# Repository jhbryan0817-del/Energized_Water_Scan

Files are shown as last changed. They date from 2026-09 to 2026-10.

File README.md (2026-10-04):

# Energized Water Scanner USV

A small unmanned surface vessel for research into detecting and mapping electrical hazards in flooded areas. Two deployable electrodes, E2/E4, measure voltage difference; the vessel must combine that measurement with validated probe pose, orientation and location. A low reading cannot establish that water is safe.

## Current state — 4 October 2026

**Electronics: Rev H engineering prototype. Mechanical assembly: live Fusion Rev I.** The PCB retains the 91 × 124 mm U-shaped perimeter, 58 × 48 mm motor opening, four mounting holes and 2 mm thickness. Six copper layers accommodate the revised electronics. The live Fusion assembly has been updated for Rev H placement, hull cleanup and corrective closure of obsolete bow/stern openings. Repository 3D exports remain historical; this update contains documentation and BOM changes only. See the [CAD audit](docs/CAD_Audit_2026-10-04.md) for verified results and remaining holds.

- [PCB design, operating limits and assembly](pcb/RevH/README.md)
- [Editable KiCad project](pcb/RevH/EWS_RevH.kicad_pro), [schematic PDF](pcb/RevH/EWS_RevH_schematic.pdf), [PCB BOM](pcb/RevH/BOM.csv), [connector pin map](pcb/RevH/PIN_MAP.md)
- [System design](docs/Design.md), [assembly and procurement](docs/Wiring_and_Assembly.md), [remaining qualification work](docs/Build_Qualification.md)
- [System BOM](BOM.csv): mechanical/harness items plus one assembled carrier. Components on that carrier are listed only in its PCB BOM.

Rev H adds a dedicated ADC per voltage range, hard-wired diagnostic/ready signals, reverse-input protection, a PCB-branch fuse and transient suppressor, battery monitoring and a dry-compartment ingress-sensor interface. The circuit targets sensitive measurements and a separate 600 V RMS, 50/60 Hz fault range. These are unqualified design targets. Bench calibration, insulation/protection review, physical fault testing and environmental qualification remain open. No validated acquisition firmware is supplied.

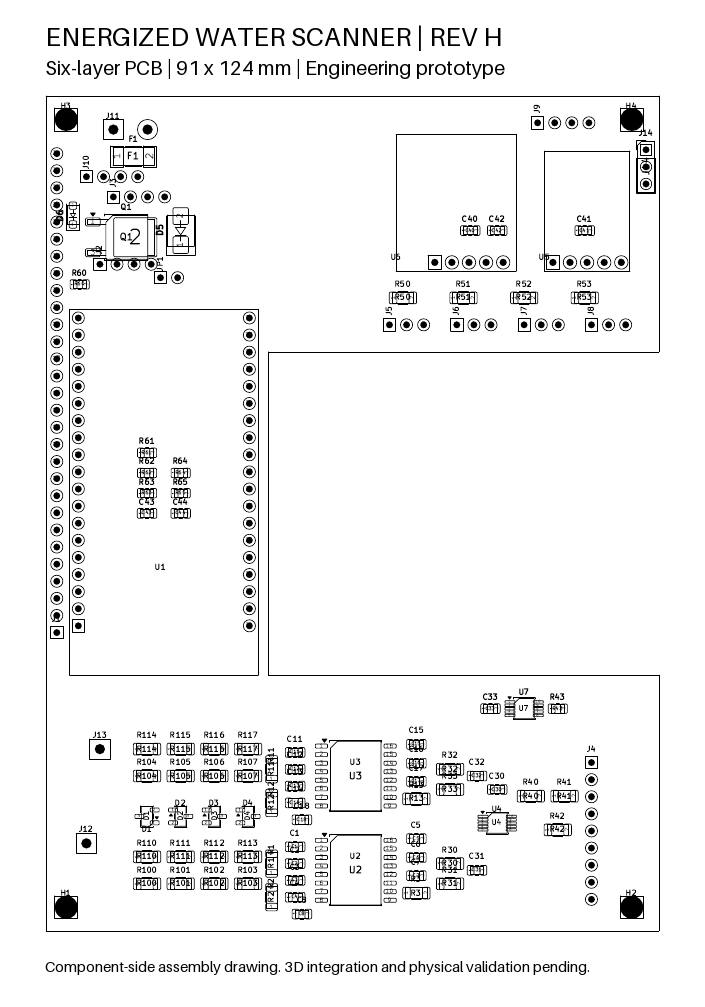
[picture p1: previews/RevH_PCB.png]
Current Rev H PCB assembly drawing


Historical Rev G previews and 3D exports are not the current mechanical authority. Use the saved live `Energized_Water_Scanner` Fusion document.

Two electrodes provide one field projection, not a full 3D field map or a direct measurement of floodwater current. Current-density estimates require independently measured conductivity and a valid field/geometry model. Fast transient measurement and an electrical-safety clearance decision are not released capabilities.

## Next milestones

1. Review the new PCB and validate components, protection, calibration, acquisition timing and fault behavior on a controlled bench.
2. Resolve the remaining mechanical holds in the CAD audit; verify actual components, wiring, seal compression and assembly tolerances.
3. Resolve actuator hardware and sealing, then test the unpowered hull for leakage and loaded flotation.
4. Implement and validate acquisition, invalid-state handling, pose/location logging and mapping; obtain appropriate laboratory qualification before hazardous exposure.

Detailed revision narratives and superseded preview images have been removed from the current documentation; Git history preserves them. Existing exported CAD releases are unchanged and superseded by the live Fusion assembly for this iteration. The `pcb/RevG` files are retained as the historical electrical baseline; use Rev H for new electronics work. Historical scripts and verification records retain their original scope and must not be treated as current acceptance evidence.

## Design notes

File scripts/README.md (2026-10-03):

# Script scope

These retained scripts belong to earlier mechanical and four-probe development revisions. They are not Rev H acquisition firmware or current acceptance tests. In particular, the four-probe gradient/pose assumptions do not apply to the present two-electrode USV. Do not run old Fusion export or mutation scripts against the live assembly without a separate revision-specific review.

Current electronics sources and validation are in `../pcb/RevH/`; current project status and outstanding work are in the root README and `../docs/`. No scripts in this directory were changed in the PCB iteration.

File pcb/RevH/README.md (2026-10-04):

# Energized Water Scanner — PCB Rev H

**Engineering prototype, 3 October 2026.** Native KiCad 10 sources for the two-electrode flood-hazard research USV. Open `EWS_RevH.kicad_pro`. This revision changes electronics only. A subsequent 4 October live Fusion Rev I iteration updates the mechanical fit representation; see [CAD audit](../../docs/CAD_Audit_2026-10-04.md). No new STEP, F3D or STL was generated.

## What changed

- U4 at I2C address **0x48** acquires the high range. New U7 at **0x49** acquires the sensitive range. Both use AIN0–AIN1; each can run continuously at 860 samples/s nominal without alternating ranges. Their clocks are independent, so this is concurrent acquisition, not phase-synchronous sampling.
- Amplifier diagnostics and conversion-ready signals are routed to ESP32 inputs. No diagnostic fly-wires are needed. The existing expansion header still exposes these nets, but they are now reserved.
- J11 feeds F1, then a P-channel reverse-polarity MOSFET Q1. D5 suppresses positive transients on protected VBAT; D6 limits gate-source voltage. Added local rail capacitors supplement the regulator modules.
- A filtered 200 kΩ/33 kΩ battery divider, with 10 kΩ series and 100 nF at GPIO32, feeds ADC1 GPIO32. Its nominal ratio is 7.0606:1 (1.190 V at an 8.4 V battery), with an approximately 41.5 Hz pole. Select and calibrate the ESP32 ADC attenuation accordingly. J14 supports a dry-compartment, 3.3 V, open-drain ingress sensor on GPIO23. This is a powered sensor interface, not a pair of bare-water electrodes.
- Existing high-voltage divider networks, isolation packages, antenna restriction, U-shaped perimeter, motor opening and mounting holes are retained. The schematic, BOM and connector map describe the same board.

## Measurement capability and limits

E2 and E4 measure **signed differential voltage** along one probe separation. The DC-coupled analog circuit also permits AC measurements; initial AC qualification is for 50/60 Hz. These electrodes do not measure total current in floodwater. Under a validated locally uniform field model, the projected field is approximately `E_parallel = V / separation`. Estimating current density further requires conductivity, `J = conductivity × E`; total current also requires a defined area and field distribution. No conductivity sensor is included in this board. Use an independently isolated conductivity instrument if that quantity is needed; the ordinary I2C header is not an isolation barrier.

Two probes can miss a field perpendicular to their separation. A scan must include validated changes in orientation, accurate pose/time/location, immersion verification and invalid-data handling. Position/heading sensors can use the available 3.3 V I2C/UART interfaces; they are not fitted by this revision. DC electrode polarization, electrode material, fouling, contact impedance and motion-generated signals must be characterized separately from electronic DC response.

| Property | High range | Sensitive range |
|---|---:|---:|
| Series resistance per electrode leg | 4 × 249 kΩ | 4 × 249 kΩ |
| Sense resistance per leg | 1 kΩ | 100 kΩ |
| Ideal attenuation before isolation | 997:1 | 10.96:1 |
| Isolation-amplifier differential gain | 2 | 2 |
| Initial measurement target | 600 V RMS, 50/60 Hz; ±850 V DC engineering ceiling | ±2 V instantaneous |
| Initial ADS1115 PGA | ±2.048 V | ±0.512 V |
| Ideal electrode-referred code step | 31.16 mV | 85.63 µV |

These are design calculations, **not demonstrated accuracy, detection thresholds or exposure ratings**. The DC ceiling gives approximately the same divider stress as the crest of the AC target; continuous DC and wet electrochemistry still require separate validation. The low range intentionally clamps during a large fault. Do not use it until recovery has been characterized. PGA changes cannot recover a clipped amplifier signal or improve the amplifier's input offset.

Each differential ADC filter is 1 kΩ + 1 kΩ with 330 nF across the inputs: ideal pole 241 Hz. The ideal analog amplitude factors are approximately 0.979 at 50 Hz and 0.970 at 60 Hz. Include ADC digital-filter response, source loading, capacitor tolerance and temperature in calibration. Neither this pole nor the converter establishes broadband anti-alias performance. Fast impulses, arbitrary inverter spectra and high-frequency hazard characterization are not released capabilities.

At 600 V RMS, the ideal high-range AMC input is 0.851 V peak; its outputs remain approximately 0.589–2.291 V around the nominal 1.44 V common mode. Normal divider dissipation is about 22.5 mW per 249 kΩ resistor. Both channels together load the electrodes by about 1.044 MΩ before clamping and approximately 1 MΩ in a large fault. The source/electrode impedance can therefore produce substantial loading error. Per-resistor working voltage does not establish pulse withstand or a single-fault rating.

The AMC3330's specified input offset alone corresponds to about 0.299 V high-range or 3.29 mV sensitive-range electrode-referred error before calibration. Bias-current mismatch, clamp leakage, resistor matching, temperature and electrode effects add further error. A fine ADC code step is not proof of microvolt detection. Validate range overlap and retain separate calibration coefficients.

## Pin assignments

See [PIN_MAP.md](PIN_MAP.md) and `PIN_MAP.csv` for every connector pin.

| ESP32 GPIO | Rev H use |
|---|---|
| 36, input only | U4 high-range READY, active low; configure ADC conversion-ready mode |
| 35, input only | U7 sensitive-range READY, active low |
| 34, input only | U2 high-range DIAG, active low |
| 39, input only | U3 sensitive-range DIAG, active low |
| 32 / ADC1 | Battery health divider; calibrate ADC attenuation and gain |
| 23 | J14 ingress-sensor input; 10 kΩ pull-up, 1 kΩ series, 100 nF filter |
| 21 / 22 | SDA / SCL, 3.3 V I2C; addresses 0x48 and 0x49 reserved |
| 25 / 26 / 27 / 14 | E2 servo / E4 servo / steering / ESC control |

ADC AIN2 and AIN3 are grounded on each converter. They can support an occasional zero-input diagnostic during a deliberately invalidated acquisition interval. They are not available as general external analog inputs. J4 exposes both isolated-side analog pairs for service, and high READY/DIAG nets; low READY is also on J1 pin 6. Never connect anything on the floating electrode side to J4 or logic ground.

## Power and assembly

Use a **2S battery only**, 8.4 V maximum normal input. An external branch fuse near the battery remains necessary to protect its harness. F1 is a provisional 3 A fast fuse for the PCB branch; coordinate its interrupt rating and time-current curve with available fault current, inrush, connector ratings and measured loads. Motor/ESC propulsion current remains in its separate fused harness. F1 does not protect that harness.

Q1 is deliberately connected with **drain/tab to BAT_FUSED and source to protected VBAT**; reversing those connections defeats reverse-input blocking. At 2 A and the 10 mΩ room-temperature resistance limit quoted at −4.5 V gate drive, its calculated conduction loss is about 40 mW, before temperature increase. This is not a thermal qualification. It is not an ideal-diode controller and does not provide general backfeed isolation between powered sources.

D5 is a 12 V standoff SMBJ12A with a specified 19.9 V clamp at its rated test current. Actual overshoot, lead inductance, pulse energy and fuse coordination need testing. It is a battery-rail suppressor, not an electrode surge arrestor. Do not apply a sustained overvoltage or infer an automotive/load-dump rating. C40/C41/C42 are 25 V X5R parts; C41/C42 sit on 5 V outputs. Check effective capacitance under bias.

Keep combined servo load initially at or below the previous 2 A development limit, with a current-limited supply, and validate stall peaks and trace/via temperatures. Do not infer board current capacity from the D24V50F5 regulator name. New capacitors beneath U5/U6 require component height ≤1.35 mm and a measured ≥2 mm module standoff; check solder joints and module underside components too.

Disconnect the battery and remove JP1 before USB service. The ESP32 can be removed from its sockets. Battery monitoring is not an autonomous cell-balancing, undervoltage-cutoff or battery-management system. Do not leave the battery connected with the MCU supply deliberately removed: divider injection into an unpowered input has not been qualified. J14 is for short internal wiring to a compatible sensor; no exposed floodwater connection or external surge rating is provided. An absent sensor can resemble a dry condition and needs a pre-run functional check.

All GPIO are 3.3 V only. Retain a WROOM DevKitC V4. Flash pins remain unavailable; boot-strapping restrictions still apply to the remaining expansion pins. U5/U6 control pins at J9 are VIN-referenced, not direct GPIO interfaces. Leave the ESC BEC lead disconnected and insulated. Never parallel the regulator outputs.

## Mechanical interface

Six copper layers, 2 mm thickness, 91 × 124 mm overall. Fusion coordinates: X −20…71, Y −62…62 mm. Motor opening: X 13…71, Y −24…24 mm. Four Ø3.4 mm holes: (−17,−58.5), (67,−58.5), (−17,58.5), (67,58.5). KiCad X = Fusion X + 50; KiCad Y = 100 − Fusion Y.

Retain the Rev G 1 mm nylon spacer arrangement, subject to actual screw engagement and underside solder-tail clearance. The existing outline and hole geometry are checked against the previous board. Populated heights, leads, connectors, ESC attachment and hatch clearance must be checked in the next Fusion iteration and on real hardware. The populated fit representation is maintained only in the live Fusion document; it is not a supplier-certified assembly or a manufacturing export.

The nominal six-layer stack uses 70 µm outer and 35 µm inner copper, dielectric layers 0.20/0.30/0.70/0.30/0.20 mm, and 0.01 mm mask per side. It totals 2.00 mm. The fabricator must confirm materials, pressed thickness, tolerances and insulation requirements. No controlled impedance is claimed. The added layers provide space through the restricted neck without reducing the input-isolation rules.

## Verification and next work

**Final automated results: zero ERC violations, zero DRC violations, zero unrouted connections and zero schematic parity issues.** A separate schematic-netlist/board/manifest comparison matched 319 connected pins. Exact Edge.Cuts geometry and the four mounting holes match Rev G. `ERC.json`, `DRC.json`, `verification.json` and `calculations.json` record the checks actually performed. ERC/DRC cannot validate a circuit topology, component derating, electrode performance or electrical safety. Custom copper rules retain the prior 8 mm floating-input-to-logic target and graded internal divider spacing. They do not derive creepage, installation category, pollution degree, laminate CTI or wet-insulation compliance.

Before hazardous exposure, obtain a qualified insulation/protection review and laboratory verification of common-mode and differential exposure, surges, single faults, resistor failures, clamp leakage/recovery, humidity/contamination, dielectric withstand, lead/enclosure insulation and thermal limits. Establish actual sensitivity and calibrated bandwidth using isolated, current-limited laboratory sources. Do not test in occupied energized water. A low reading, broken lead, dry probe, stalled conversion or saturated channel must never be interpreted as safe water.

Firmware is deferred. Its contract is: configure both converters explicitly; timestamp each ready event; detect stale data, clipping, DIAG faults, startup and recovery; invalidate health failures; calculate DC and AC quantities separately; log pose/location and uncertainty. No minimum detectable field or alarm threshold is released.

## Primary references

- [TI AMC3330](https://www.ti.com/lit/ds/symlink/amc3330.pdf): isolated amplifier limits, input/output behavior and supply network.
- [TI ADS1115](https://www.ti.com/lit/ds/symlink/ads1115.pdf): PGA, MUX, I2C addressing and conversion-ready timing.
- [Diodes DMPH3010LK3](https://www.diodes.com/datasheet/download/DMPH3010LK3.pdf): MOSFET pinout and ratings.
- [Littelfuse SMBJ](https://m.littelfuse.com/~/media/electronics/datasheets/tvs_diodes/littelfuse_tvs_diode_smbj_datasheet.pdf.pdf) and [451/453 fuse series](https://www.littelfuse.com/~/media/electronics/datasheets/fuses/littelfuse_fuse_451_453_datasheet.pdf.pdf).
- [Espressif DevKitC V4](https://docs.espressif.com/projects/esp-dev-kits/en/latest/esp32/esp32-devkitc/user_guide.html), [Pololu logic module](https://www.pololu.com/product/2831), [Pololu servo module](https://www.pololu.com/product/2851).

Native files were edited through KiCad's pcbnew API and checked with kicad-cli 10.0.6. The local IPC server answered the version query but returned no open-document handler. No claim of live IPC board editing or physical testing is made.

The native schematic uses project-local functional pin-map symbols with named global nets, continuing the previous project style. It is electrically editable and checked for board parity; it is not a substitute for an independent circuit review. No new fabrication order or manufacturing release is authorized by these reports.

Checks use the configured project rules. The reports list inherited ignored checks, including missing courtyards, track-to-via centering and footprint filters. No new violation was excluded to obtain the result. Mechanical fit of parts above sockets or module standoffs remains a separate check. The archive intentionally excludes 3D models; references inherited from Rev G are represented in the live Fusion fit assembly, with provisional envelopes identified in the CAD audit.

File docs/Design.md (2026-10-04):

# Current system design

The USV is intended to detect and map electrical hazards remotely in flooded areas. The hull is 320 mm long, with a documented 125.2 mm bottom beam and 170 mm hatch flange. Only the inner E2/E4 probe mechanisms remain. Each uses a dry HS-65HB servo and a nominal timing transmission to a sealed shaft and insulating 166 mm arm. Nominal exposed-head separation at symmetric deployment is 114.6 mm; actual submerged geometry must be measured. Varying orientation is necessary to address the blind direction of a single electrode pair.

The current mechanical authority is live Fusion Rev I; see the [CAD audit](CAD_Audit_2026-10-04.md). The U-shaped carrier replaces the former electronics tray; the ESP32 is socketed on it. The old rear controller shelf and electronics capture bridges are absent. The battery cradle, propulsion mounts/tube, steering saddle, rudder, wet-channel roofs, probe covers and sealing features remain functional. There are 13 documented print bodies in the existing Rev G release. The Rev H electronics iteration did not change geometry. This subsequent Rev I mechanical iteration cleans the exterior hull relief and integrates a Rev H fit representation without exporting 3D files.

The two electrode leads feed protected sensitive and high-voltage paths through separate isolated amplifiers. Rev H uses one ADC per range and wired health/ready signals. Logic and servo supplies remain separate; propulsion current stays in an external fused harness. Refer to the [PCB guide](../pcb/RevH/README.md) for the authoritative electrical circuit, pin map, measurement limits and board interface.

The measurement is differential voltage. A field estimate requires electrode spacing and pose; current density further requires conductivity. DC electrode polarization, fouling, motion, field orientation and probe immersion can invalidate apparent electrical readings. No conductivity, GNSS or heading module is fitted in the current BOM. Expansion interfaces provide room for subsequent integration, with isolation required for any additional wet sensing interface.

Current CAD images are geometric references, not photographs of a built vessel. CAD fit, electrical rule checks and nominal supplier dimensions do not establish waterproofness, electrical safety, reliable actuation or flotation. The [qualification plan](Build_Qualification.md) separates those remaining tasks.

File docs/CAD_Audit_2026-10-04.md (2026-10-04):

# Live Fusion CAD audit — 4 October 2026

Status: CAD iteration saved in Fusion; prototype qualification remains open. The active document reports isSaved=true and isModified=false after the final inspection.

## Sources and scope

The live `Energized_Water_Scanner` Fusion document is the mechanical authority. Repository STEP, F3D and STL files are historical and were not used as the current geometry. No new 3D exports are part of this iteration. Electronics remain Rev H and were inspected read-only from the 3 October engineering package.

PCB SHA-256: `632b1010472cf8494d2aebf4daa54a68f1dddf9a889bf5f3b36ea65f5c8ed012`. The board contains 100 footprints: 99 manifest entries plus the M1 ESC mounting allocation. Manifest placement coordinates match the board. Explicitly unconnected ESP32 flash pins and J8 pin 2 are intentional. No circuit, routing or footprint change is authorized by this mechanical iteration.

## Hull cleanup

The initial hull was a single solid with 902 BRep faces, including 582 planes, 154 cylindrical faces and 166 NURBS faces. Faces are not equivalent to mesh triangles or leaks. Adjacent coplanar-face inspection found no simple redundant planar seams to merge.

Removing the raised lettering on the negative-Y exterior panel reduced the hull to 667 faces (235 fewer, 26.1%). The underlying panel plane was retained. Volume changed from 543.530832 to 543.175890 cm³, a removal of 354.942 mm³ of exterior relief. The result is still one solid and one lump, with the original overall bounding box. The original hull remains hidden as `ARCHIVE_RevG_Hull_DO_NOT_BUILD`; that initial replacement was subsequently superseded by the opening repair below.

A delete-and-heal operation on a duplicate caused Fusion to close. The saved original was reopened, and the successful cleanup used a bounded Boolean cut in temporary geometry before adding the verified result. This is a limited simplification, not a wholesale hull reconstruction. Hundreds of remaining faces encode mounting bosses, pilots, channels, roof boundaries and other functional geometry.

## Corrective bow and stern repair

The initial audit missed large openings at the bow and stern. A valid solid and a PCB clearance pass did not establish continuity of the water boundary. The user identified this omission; the initial hull cleanup must not be interpreted as closure of those openings.

The active hull is now `PRINT_01_Hull_shell_RevI_repaired`. Obsolete pockets that broke through the transom and bow have been closed with continuous skins following the adjacent hull planes. The starboard stern chine breakthrough was also closed. The transom and bow skins span 3.3 mm in X (approximately 3.2 mm normal thickness); the chine repair uses 3 mm normal thickness. Existing adjacent geometry remains, so this is not a uniform-wall guarantee. The 7 mm steering passage and four 2.5 mm rudder-bracket bores are retained. No component was moved, and the probe deployment channels remain open intentionally.

Final geometry: **694 faces**, one solid, one lump, one shell, volume **550.479057 cm³**. That is 208 fewer faces than the original 902 (23.1%). Two enclosed remnants of obsolete bow pilot bores were filled rather than leaving trapped cavities. The initial and intermediate hulls are hidden archive components, not additional build parts.

Verification includes exterior views of both ends, Boolean intersection checks of the final hull against 316 nearby retained bodies (zero intersections above 0.0001 mm³), and a 1 mm grid through the repaired wall interiors. The grid excludes functional bores and panel boundaries: 7,078 transom points and 6,670 bow points. Missing material dropped from 1,443 and 320 sampled points respectively to zero. This is a targeted continuity check, not an exhaustive leak-path proof or physical pressure test. Dynamic seals, fasteners, feedthroughs, print porosity and the hatch still require the qualification below.

## PCB mechanical contract

Board: 91 × 124 × 2 mm, X −20…71 mm, Y −62…62 mm. Opening: X 13…71, Y −24…24 mm. Four Ø3.4 mounting holes at (−17,−58.5), (67,−58.5), (−17,58.5), (67,58.5). PCB underside Z=33 mm, top Z=35 mm in the retained assembly coordinate system. KiCad coordinates convert by X_Fusion=X_KiCad−50 and Y_Fusion=100−Y_KiCad.

The fit representation is not a fabrication model: it represents board outline and mounting holes, package bodies, module/header envelopes and explicitly labelled provisional allocations. Copper and individual electrical drills are not rendered. The KiCad board remains authoritative for manufacturing.

## Verified configuration and clearance result

The saved Fusion document is `Energized_Water_Scanner`, data-file ID `urn:adsk.wipprod:dm.lineage:ybjJzCieRSuTtp7MFNwhCA`. The active `PCB_RevH_populated_RevI_fit` contains 243 bodies representing the carrier and all 95 populated references. The preceding PCB and hull are retained as hidden archive components; the imported package library is hidden and is not an assembly item.

Q1, D5, D6 and the 0805 resistor use installed KiCad package geometry. Existing module/header representations were reused at Rev H placements. F1 is a provisional 6.2 × 2.8 × 3.1 mm envelope, not a supplier maximum-tolerance envelope. J11–J13 represent pigtail termination space, not complete wire routes. J14 uses a generic header representation; verify the selected connector and mating half. Module bodies and sockets must be checked against purchased parts.

A bounding-box broad phase followed by temporary BRep Boolean intersections found **zero positive-volume intersections above 0.0001 mm³** between the 243 PCB-fit bodies and the other retained modeled bodies, including the hidden hatch/gasket. Archive and library components were excluded. This does not test contacts, PCB-to-package overlaps, cable routing, tool access, motion sweeps or manufacturing tolerances. The hull has one solid, one shell and one lump. Its intentional functional passages were retained; no claim is made that every apparent opening has been sealed.

The 1 mm spacers place the PCB underside at Z33 mm. Modeled header tails reach Z32.2 mm, leaving only 0.2 mm above the Z32 support-top plane where that plane is present. This is a nominal geometry observation, not adequate guaranteed clearance for solder fillets and print variation. Resolve the stack with the actual connectors before manufacture.

## Water boundary and assembly risks

| Priority | Interface | Finding and required disposition |
|---|---|---|
| High | Propulsion shaft | A bonded stern tube does not seal the annulus between rotating shaft and tube. Qualify a real dynamic seal/lubrication arrangement and axial retention before immersion. |
| High | Probe shaft cartridges | Nominal seal, shaft and bushing envelopes do not establish water duty, shaft finish, interference fits, wear or drag. Release machined cartridge tolerances against the selected seal supplier and shaft specification. |
| High | Steering boot | The current boot is an allocation, not a selected and tested water seal. Verify both retained ends, linkage sweep, buckling and repeated cycles. |
| High | Lead feedthroughs | Potting requires validated bond to the actual wire jacket and printed/coated hull, void control and strain relief. Protect the flex loop throughout probe travel. |
| High | Hull and wet-channel roofs | A watertight BRep solid does not prove the assembled dry compartment is sealed. Inspect all through passages, roof joints and fastener breakthroughs, then perform unpowered leak tests after coating. |
| Medium | Main hatch | The initial CAD shows a 2 mm gasket at Z68…70 and cover at Z70…73: nominal uncompressed geometry, not demonstrated gasket squeeze. Select material and compression specification, verify flatness and use controlled tightening/appropriate stops. |
| Medium | PCB underside | Retained 1 mm spacers leave little margin for solder tails, solder fillets and printed boss variation. Trim/inspect leads and validate the complete assembled stack; do not deepen wet-side blind pilots to gain screw engagement. |
| Medium | Regulator modules | C40/C41/C42 occupy space under modules. Require ≥2 mm actual clearance to the module underside, capacitor height ≤1.35 mm, and allowance for solder and tolerances. Nominal gap is not a tolerance analysis. |
| Medium | Probe service covers | They are removable access covers, not independently sealed compartments. Retain connector access and validate E4 inward-then-upward removal with wiring installed. |
| Medium | Belts and pulleys | Smooth pulley bodies do not specify tooth profile, horn adaptation, belt availability, tension adjustment or axial retention. Confirm one complete actuator before duplicating it. |
| Medium | Battery and ESC | Confirm strap routing, flush screw heads, abrasion protection and removal path. Qualify the ESC attachment adhesive and temperature; keep all wiring off gasket lands. |

No IP rating, full-motion assembly acceptance, minimum wall-thickness certification or physical leak result is claimed. Before a build release, perform tolerance-stack review with supplier tolerances and the actual printing/machining process. Test the empty hull and each dynamic penetration in unenergized water, then repeat after service and actuation cycles. Establish freeboard and stability using the actual completed mass.

## Read-only electrical assessment

The two isolated AMC3330 paths and two ADS1115 converters support concurrent sensitive and high-range acquisition of signed probe voltage. The DC-coupled circuit permits DC and initial 50/60 Hz AC qualification. The design targets ±2 V instantaneous on the sensitive path and 600 V RMS at 50/60 Hz on the high path; ±850 V DC is an engineering ceiling requiring separate qualification. These are not tested operating or safety ratings.

Each ADC can run at nominal 860 samples/s, but the clocks are independent. Approximate ideal electrode-referred steps are 85.63 µV (sensitive) and 31.16 mV (high). AMC3330 maximum offset alone corresponds to about 3.29 mV and 0.299 V respectively before calibration. Resolution must not be represented as detection sensitivity.

The circuit measures one voltage difference, not total water current, earth-referenced potential or a complete field vector. A perpendicular field, dry/open/fouled probe, clipping or stale conversion can defeat inference from a low reading. Source impedance and approximately 1 MΩ input loading, DC polarization, motor noise, temperature, range recovery and finite bandwidth require measurement. No conductivity, GNSS or heading sensor is fitted, and validated acquisition firmware is absent.

Within the existing form factor, prioritize calibration and temperature characterization; timestamped READY/DIAG monitoring; invalid-state handling; DC/AC separation; range-overlap and overload-recovery checks; pre-run probe and ingress-sensor functional tests; motor-quiet acquisition intervals; protected harness routing; and pose/location integration after connector, power and clearance checks. Probe continuity/immersion sensing may need additional isolated circuitry and is not furnished merely by the current DIAG signals.

References: [Rev H circuit and limits](../pcb/RevH/README.md), [TI AMC3330](https://www.ti.com/lit/ds/symlink/amc3330.pdf), [TI ADS1115](https://www.ti.com/lit/ds/symlink/ads1115.pdf). Component isolation certification does not rate the complete wet instrument.

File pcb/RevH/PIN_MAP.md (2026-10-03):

# Rev H connector pin map

Component-side view; square pad identifies pin 1. All GPIO are 3.3 V only. GPIO34/35/36/39 and GPIO32/23 have onboard functions; the expansion header does not make them free GPIO.

| Connector | Pin | Net | Restriction |
|---|---:|---|---|
| J1 | 1 | 3V3 |  |
| J1 | 2 | EN |  |
| J1 | 3 | ADC_READY | GPIO36: high ADC ready, reserved input |
| J1 | 4 | LO_DIAG | GPIO39: low amplifier diagnostic, reserved input |
| J1 | 5 | HI_DIAG | GPIO34: high amplifier diagnostic, reserved input |
| J1 | 6 | LO_READY | GPIO35: low ADC ready, reserved input |
| J1 | 7 | GPIO32 | Battery monitor ADC1 input; do not drive externally |
| J1 | 8 | GPIO33 |  |
| J1 | 9 | GPIO25 |  |
| J1 | 10 | GPIO26 |  |
| J1 | 11 | GPIO27 |  |
| J1 | 12 | GPIO14 |  |
| J1 | 13 | GPIO12 | Boot strap: attached circuitry must preserve boot levels |
| J1 | 14 | GND |  |
| J1 | 15 | GPIO13 |  |
| J1 | 16 | GPIO23 | Ingress sensor input; do not drive from expansion |
| J1 | 17 | GPIO22 |  |
| J1 | 18 | GPIO1 |  |
| J1 | 19 | GPIO3 |  |
| J1 | 20 | GPIO21 |  |
| J1 | 21 | GPIO19 |  |
| J1 | 22 | GPIO18 |  |
| J1 | 23 | GPIO5 | Boot strap: attached circuitry must preserve boot levels |
| J1 | 24 | GPIO17 |  |
| J1 | 25 | GPIO16 |  |
| J1 | 26 | GPIO4 |  |
| J1 | 27 | GPIO0 | Boot strap: attached circuitry must preserve boot levels |
| J1 | 28 | GPIO2 | Boot strap: attached circuitry must preserve boot levels |
| J1 | 29 | GPIO15 | Boot strap: attached circuitry must preserve boot levels |
| J2 | 1 | GND |  |
| J2 | 2 | 3V3 |  |
| J2 | 3 | GPIO21 |  |
| J2 | 4 | GPIO22 |  |
| J3 | 1 | GND |  |
| J3 | 2 | GPIO1 |  |
| J3 | 3 | GPIO3 |  |
| J3 | 4 | EN |  |
| JP1 | 1 | LOGIC_5V |  |
| JP1 | 2 | ESP_5V |  |
| J4 | 1 | GND |  |
| J4 | 2 | 3V3 |  |
| J4 | 3 | HI_DIAG | GPIO34: high amplifier diagnostic, reserved input |
| J4 | 4 | LO_DIAG | GPIO39: low amplifier diagnostic, reserved input |
| J4 | 5 | ADC_READY | GPIO36: high ADC ready, reserved input |
| J4 | 6 | HI_ADC_P |  |
| J4 | 7 | HI_ADC_N |  |
| J4 | 8 | LO_ADC_P |  |
| J4 | 9 | LO_ADC_N |  |
| J5 | 1 | GND |  |
| J5 | 2 | SERVO_5V |  |
| J5 | 3 | GPIO25 |  |
| J6 | 1 | GND |  |
| J6 | 2 | SERVO_5V |  |
| J6 | 3 | GPIO26 |  |
| J7 | 1 | GND |  |
| J7 | 2 | SERVO_5V |  |
| J7 | 3 | GPIO27 |  |
| J8 | 1 | GND |  |
| J8 | 2 | ESC_BEC_NC | Do not connect ESC BEC |
| J8 | 3 | GPIO14 |  |
| J9 | 1 | REG_SHDN | VIN referenced: no direct GPIO connection |
| J9 | 2 | REG_PG | VIN referenced: no direct GPIO connection |
| J9 | 3 | SERVO_EN | VIN referenced: no direct GPIO connection |
| J9 | 4 | GND |  |
| J10 | 1 | GND |  |
| J10 | 2 | 3V3 |  |
| J10 | 3 | LOGIC_5V |  |
| J10 | 4 | GND |  |
| J11 | 1 | BAT_RAW | 2S battery, externally fused; 8.4V normal maximum |
| J11 | 2 | GND |  |
| J12 | 1 | E2 | Floating electrode input; insulation and strain relief required |
| J13 | 1 | E4 | Floating electrode input; insulation and strain relief required |
| J14 | 1 | GND |  |
| J14 | 2 | 3V3 |  |
| J14 | 3 | LEAK_EXT | Internal 3.3V open-drain sensor only; never an external water electrode |

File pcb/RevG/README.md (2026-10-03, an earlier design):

# Rev G electrical baseline

Historical files retained to document the PCB represented by the existing Rev G mechanical model. Use [Rev H](../RevH/README.md) for current electronics, BOM, wiring and validation. No Rev G CAD or 3D file was changed in the Rev H iteration.

Rev G used one multiplexed ADS1115 for two isolated ranges, unconnected controller diagnostic inputs, and unprotected battery polarity. Its reports apply only to that saved revision. The old manufacturing files are not a current fabrication release. Detailed revision history remains in Git.

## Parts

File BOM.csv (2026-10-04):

ID | Item | Quantity | Purpose | Status | Notes | Source / reference
BOM-004 | Hobbywing QuicRun WP-1625 brushed ESC (30120000) | 1.0 | RC boat | Fit verification required | Confirm exact supplier revision and availability. | Hobbywing QuicRun WP-1625 30120000 有刷电调
BOM-005 | Mabuchi RS-380PH-4045 motor | 1.0 | RC boat | Fit verification required | Confirm exact supplier revision and availability. | Mabuchi RS-380PH-4045 万宝至 马达
BOM-006 | Krick 65220 Eco M2 shaft/stern tube assembly | 1.0 | RC boat | HOLD: internal shaft sealing | Qualify shaft-to-tube sealing/lubrication separately from hull bond. | Krick 65220 M2 153mm 船轴 艉轴套件
BOM-007 | Krick 63800 bridge coupling connector | 1.0 | RC boat | Fit verification required | Confirm exact supplier revision and availability. | Krick 63800 船模 联轴器 连接件
BOM-008 | Krick 63823 2.3 mm coupling insert | 1.0 | RC boat | Fit verification required | Confirm exact supplier revision and availability. | Krick 63823 2.3mm 联轴器 接头
BOM-009 | Krick 63820 2.0 mm coupling insert | 1.0 | RC boat | Fit verification required | Confirm exact supplier revision and availability. | Krick 63820 2.0mm 联轴器 接头
BOM-010 | Krick/Graupner 2307.30 propeller, 30 mm RH M2 | 1.0 | RC boat | Fit verification required | Confirm exact supplier revision and availability. | Graupner Krick 2307.30 30mm M2 右旋 三叶螺旋桨
BOM-011 | Genuine TowerPro SG90 Digital servo | 1.0 | RC boat | Fit verification required | Confirm exact supplier revision and availability. Steering servo only; actual horn and travel require verification. | TowerPro SG90 Digital 正品 数字舵机
BOM-012 | Gens Ace GEA222S30X6GT 2200 mAh 2S 30C XT60 LiPo | 1.0 | Both | Fit verification required | Confirm exact supplier revision and availability. | Gens Ace GEA222S30X6GT 2S 2200mAh 30C XT60 航模电池
BOM-014 | Hitec HS-65HB probe servo with supplied horn | 2 | Electricity detection | Fit verification required | Dry only; additional to steering servo. Horn-to-pulley adapter must match actual supplied horn. | https://www.hiteccs.com/public/uploads/data_sheet/HCS_HS-65HB_Specsheetv2.2_10-1729887930.pdf
BOM-016 | SKF 6 x 16 x 7 HMSA10 RG radial seal | 2 | Electricity detection | HOLD: water-duty qualification | Nominal candidate; water duty, lubricant, spring, shaft finish and seal drag not qualified. | https://www.skf.com/mm/09433a92e9164581
BOM-017 | igus GFM-0608-06 flanged shaft bushing | 2 | Electricity detection | Fit verification required | 6 mm shaft / 8 mm housing, 12 mm flange; verify installed fits. | https://www.igus.com/ContentData/Products/Downloads/iglide_G300_FM_USen.pdf
BOM-018 | Machined POM-C probe seal cartridge | 2 | Electricity detection | HOLD: machining drawing | Two retained E2/E4 cartridge geometries. Precision tolerances and counterfaces require release; do not print seal seats.
BOM-019 | Cartridge face gasket, 1 mm silicone sheet | 2 | Electricity detection | Fit verification required | CAD compressed thickness 0.75 mm; retain complete closed perimeter. Polymax 3043956 candidate. | https://www.polymax.co.uk/media/documents/Datasheet/platinum-cured-silicone-sheet-clear-1000-1-3043956.pdf
BOM-020 | 316 stainless probe output shaft, diameter 6 mm | 2 | Electricity detection | HOLD: shaft interface | Two retained rear shafts, approximately 35mm nominal. Confirm actual length, surface finish, coupling and axial retention.
BOM-021 | 316 stainless arm cross-pin, diameter 2 x 22 mm | 2 | Electricity detection | HOLD: pin retention | Retained-pin solution and installation access must be proven.
BOM-022 | A4 stainless DIN84 M4 x 12 tip electrode screw | 2 | Electricity detection | Fit verification required | Replaces fixed-hull electrode bolt set; nominal head diameter 7 x 2.6 mm. | https://www.trfastenings.com/Products/Catalogue/Screws-and-Bolts/Machine-Screws/Cheese-Head/Slotted-Drive/TR00007556
BOM-023 | A4 DIN934 M4 tip nut | 2 | Electricity detection | Fit verification required | Verify actual nut and terminal stack fits the arm-tip potting pocket.
BOM-024 | M4 tip electrical terminal | 2 | Electricity detection | HOLD: actual terminal fit | Select to fit diameter 9 mm pocket and wire; no old large hull lug substitution.
BOM-025 | 20-tooth, 2 mm pitch, 6 mm belt-width pulley | 4 | Electricity detection | HOLD: select timing transmission | Smooth CAD allocations only; matched supplier profile, bore and retention remain unresolved.
BOM-026 | 96 mm nominal pitch-length x 6 mm timing belt | 2 | Electricity detection | HOLD: select timing transmission | 28 mm centers and 1:1 ratio are allocations; confirm actual supplier availability/tension.
BOM-027 | Upper journal bushing, OD8 / ID6 x 6 mm | 2 | Electricity detection | HOLD: journal interface | Radial-load support allocation; select actual bearing/fit/retention.
BOM-028 | Upper journal shaft, diameter 6 mm | 2 | Electricity detection | HOLD: journal interface | Use station-specific CAD length; axial retention and pulley interfaces not released.
BOM-029 | Stock servo horn-to-pulley adapter | 2 | Electricity detection | HOLD: design after horn survey | Requires actual Micro25T horn survey; no printable spline supplied.
BOM-030 | 3M DP270 potting compound | 1 | Electricity detection | HOLD: wet bond qualification | One consumable lot for two roof entries and two tip encapsulations. Qualify actual dispensed quantity, jacket/PETG adhesion and immersion. | https://multimedia.3m.com/mws/media/1235390O/dp270-technical-data-sheets.pdf
BOM-031 | Flexible insulated electrode lead | 2 | Electricity detection | HOLD: flex/immersion qualification | Two runs; cut on assembled prototype. Existing OD1.12mm candidate feedthrough reference; insulation voltage, immersion and flex life remain unqualified. | https://www.alphawire.com/en/products/wire/hook-up-wire/premium/1854
BOM-032 | Probe-servo service connectors and fused harness | 1 | Electricity detection | HOLD: harness selection | Two probe servo disconnects plus appropriate harness protection and strain relief; verify ratings and lengths.
BOM-034 | Shared fused battery distribution harness | 1 | Both | HOLD: harness/protection selection | XT60 input, separately fused logic/servo and propulsion branches, switch, wiring and heat-shrink. The power branches share battery ground; no galvanic isolation is implied. Select ratings against measured fault and load currents.
BOM-035 | ESC adapter and motor terminations | 1 | RC boat | HOLD: connector selection | One set: correct XT60 distribution-to-small-Tamiya polarity and matching 4 mm motor bullet terminals.
BOM-036 | Compatible 2S LiPo balance charger | 1 | Both | Select / check owned equipment | External support equipment; omit purchase if already owned. Select compatible charger.
BOM-037 | Main hatch continuous shaped gasket, 2 mm | 1 | Both | Fit verification required | 2 mm nominal uncompressed gasket. CAD does not establish compression; qualify material, squeeze, cover flatness and repeated sealing.
BOM-038 | Hatch M3 x 10 screws | 10 | Both | Fit verification required | Starting length only. Confirm compressed gasket stack, blind engagement and bottoming margin; do not use screw torque as proof of gasket compression.
BOM-039 | Internal probe-cover M3 x 10 screws | 8 | Electricity detection | Fit verification required | Updated from M3 x 8 to suit 5 mm covers; nominal 5 mm engagement into 7 mm pilots; verify printed thread life.
BOM-040 | Cartridge-retention M3 x 8 screws | 8 | Electricity detection | Fit verification required | 3 mm flange + 0.75 mm gasket; 5 mm pilot. M3x8 gives 4.25 mm engagement, 0.75 mm tip gap. Verify.
BOM-041 | Probe-servo mounting M2 x 6 screws | 4 | Electricity detection | Fit verification required | Starting length; two per servo, verify actual supplied lugs.
BOM-047 | Battery cradle flush M2 x 6 screws | 4 | Both | Fit verification required | Four countersunk locations; heads must remain below battery seating surface. Verify 1 mm nominal pilot tip margin.
BOM-048 | Battery retention straps | 2 | Both | Fit verification required | Pass through retained slots; do not compress or abrade LiPo pack.
BOM-049 | Motor support M3 x 8 screws | 4 | RC boat | Fit verification required | Existing bolt positions/grip preserved by reinforcement reliefs.
BOM-050 | Motor face M2.6 x 6 screws | 2 | RC boat | Fit verification required | Verify Mabuchi maximum screw penetration.
BOM-051 | Nonconductive motor cradle liner, 0.4 mm | 1 | RC boat | Fit verification required | One fitted liner; temperature and material qualification required.
BOM-052 | Steering saddle M3 x 8 screws | 4 | RC boat | Fit verification required | Starting length; verify pilot engagement.
BOM-053 | Steering servo M2 mounting screws | 2 | RC boat | Fit verification required | Select length against actual SG90 lugs and support.
BOM-054 | Rudder bracket M3 transom screws | 4 | RC boat | Fit verification required | bores stop at X=193 mm, with 3 mm caps. Select length for tip X>=193.75 mm; verify engagement.
BOM-055 | Rudder stock, diameter 3 x 86 mm | 1 | RC boat | Fit verification required | Metal stock; cross-hole and retention match actual tiller.
BOM-056 | Rudder tiller cross-pin, diameter 1.2 x 8 mm | 1 | RC boat | Fit verification required | Retain positively; nominal CAD envelope.
BOM-057 | Rudder stock stop collar, diameter 8 x 5 mm envelope | 1 | RC boat | HOLD: collar selection | Must fit 3 mm stock; actual supplier/locking method not selected.
BOM-058 | M2 steering dogleg pushrod and end fittings | 1 | RC boat | HOLD: linkage validation | One linkage set; fabrication geometry, stiffness, horn fit and full steering sweep require physical validation.
BOM-059 | Steering pushrod bellows / boot | 1 | RC boat | HOLD: boot selection | 7 mm seat / 10 mm flange envelope; select real water-sealing part and verify travel.
BOM-061 | Hull coating and stern-tube sealant | 1 | Both | Fit verification required | One consumable lot; quantities/process TBD. Qualify FDM porosity and penetrations.
BOM-062 | Insulating cable ties / strain relief supplies | 1 | Both | Fit verification required | One consumable lot; ties up to 2.5 mm for modeled slots.
BOM-063 | PRINT_01 live Fusion Rev I hull | 1 | Both | Fit prototype; physical qualification pending | Use PRINT_01_Hull_shell_RevI_repaired in the saved live Fusion document. Obsolete bow/transom pockets and starboard chine breakthrough closed; exterior lettering removed. Historical exports are superseded. No new 3D export supplied. | docs/CAD_Audit_2026-10-04.md
BOM-064 | PRINT_02 Removable hatch | 1 | Both | Fit prototype; physical qualification pending | Use the corresponding retained part in the live Fusion assembly. Historical exports are not the current assembly authority; verify material, fit and sealing before use. | docs/CAD_Audit_2026-10-04.md
BOM-066 | PRINT_04 Reinforced battery cradle | 1 | Both | Fit prototype; physical qualification pending | Use the corresponding retained part in the live Fusion assembly. Historical exports are not the current assembly authority; verify material, fit and sealing before use. | docs/CAD_Audit_2026-10-04.md
BOM-067 | PRINT_09 Rudder transom bracket | 1 | RC boat | Fit prototype; physical qualification pending | Use the corresponding retained part in the live Fusion assembly. Historical exports are not the current assembly authority; verify material, fit and sealing before use. | docs/CAD_Audit_2026-10-04.md
BOM-068 | PRINT_11 Reinforced motor face mount | 1 | RC boat | Fit prototype; physical qualification pending | Use the corresponding retained part in the live Fusion assembly. Historical exports are not the current assembly authority; verify material, fit and sealing before use. | docs/CAD_Audit_2026-10-04.md
BOM-069 | PRINT_14 Reinforced motor lower cradle | 1 | RC boat | Fit prototype; physical qualification pending | Use the corresponding retained part in the live Fusion assembly. Historical exports are not the current assembly authority; verify material, fit and sealing before use. | docs/CAD_Audit_2026-10-04.md
BOM-070 | PRINT_16 Rudder blade | 1 | RC boat | Fit prototype; physical qualification pending | Use the corresponding retained part in the live Fusion assembly. Historical exports are not the current assembly authority; verify material, fit and sealing before use. | docs/CAD_Audit_2026-10-04.md
BOM-071 | PRINT_17 Rudder tiller | 1 | RC boat | Fit prototype; physical qualification pending | Use the corresponding retained part in the live Fusion assembly. Historical exports are not the current assembly authority; verify material, fit and sealing before use. | docs/CAD_Audit_2026-10-04.md
BOM-076 | PRINT_23 and PRINT_25 internal probe covers | 2 | Electricity detection | Fit prototype; physical qualification pending | Use the corresponding retained part in the live Fusion assembly. Historical exports are not the current assembly authority; verify material, fit and sealing before use. | docs/CAD_Audit_2026-10-04.md
BOM-077 | PRINT_27 and PRINT_29 insulating probe arms | 2 | Electricity detection | Fit prototype; physical qualification pending | Use the corresponding retained part in the live Fusion assembly. Historical exports are not the current assembly authority; verify material, fit and sealing before use. | docs/CAD_Audit_2026-10-04.md
BOM-078 | PRINT_30 Steering service saddle | 1 | RC boat | Fit prototype; physical qualification pending | Use the corresponding retained part in the live Fusion assembly. Historical exports are not the current assembly authority; verify material, fit and sealing before use. | docs/CAD_Audit_2026-10-04.md
PCB-H | Rev H assembled carrier | 1 | Both | Engineering prototype; not qualified | 95 populated electrical references in pcb/RevH/BOM.csv; add two sockets, one shunt and two module standoff sets from ASSEMBLY_BOM.csv. External harness, spacers, screws and electrode leads are counted in system rows; do not duplicate. | pcb/RevH/README.md
M-H1 | M3 nylon PCB spacers, 1 mm | 4 | Both | Fit verification required | Retained 1 mm spacer allocation; solder-tail and boss clearances require assembled inspection. No blanket approval for untrimmed pins. | pcb/RevH/README.md
M-H2 | M3 nylon PCB screws | 4 | Both | HOLD: actual length | Select engagement against actual spacer/2 mm PCB/blind pilot stack. | pcb/RevH/README.md
M-H3 | 3M SJ3550 mating pieces, 22 x 29 mm | 2 | Both | HOLD: retention and thermal tests | Existing ESC attachment concept, nominal 5.8 mm engaged. | pcb/RevH/README.md
S-H1 | Optional dry-compartment 3.3 V open-drain ingress sensor | 1 | Both | HOLD: select compatible device | J14 interface only; sensor is not supplied or qualified. No external water-electrode connection. | pcb/RevH/README.md

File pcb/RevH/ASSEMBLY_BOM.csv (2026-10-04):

item | quantity | requirement
ESP32 female sockets | 2 | 1x19 2.54mm; 25.4mm row spacing; verify underside gap above health passives
Module standoff sets | 2 | Insulated; at least 2mm clear below regulators including solder tails
JP1 shunt | 1 | 2.54mm removable; remove before USB
PCB nylon spacers | 4 | Reference only: system BOM M-H1; M3 1mm nominal, validate solder tails and screw engagement
PCB nylon screws | 4 | Reference only: system BOM M-H2; select length against actual blind pilots
Electrode pigtails | 2 | Reference only: system BOM BOM-031; rated insulation, strain relief and wet-entry qualification required
External battery branch fuse and harness | 1 | Reference only: system BOM BOM-034; select ratings against measured load and fault current

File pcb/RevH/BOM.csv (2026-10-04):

ref | value | mpn | footprint | note | procurement_status | source
U1 | ESP32-DevKitC V4 WROOM | ESP32-DevKitC-32E | EWS:U1 | WROOM DevKitC V4; confirm module/38-pin interface; two 1x19 sockets required | Selected candidate; verify exact supplier drawing and availability | https://docs.espressif.com/projects/esp-dev-kits/en/latest/esp32/esp32-devkitc/user_guide.html
J1 | EXPANSION_3V3_ONLY |  | EWS:J1 |  | HOLD: select manufacturer part against value, footprint and ratings
J2 | I2C_3V3 |  | EWS:J2 |  | HOLD: select manufacturer part against value, footprint and ratings
J3 | UART_RESET |  | EWS:J3 |  | HOLD: select manufacturer part against value, footprint and ratings
JP1 | REMOVE_FOR_USB |  | EWS:JP1 |  | HOLD: select manufacturer part against value, footprint and ratings
U2 | AMC3330DWER | AMC3330DWER | EWS:U2 |  | Selected candidate; verify exact supplier drawing and availability | https://www.ti.com/lit/ds/symlink/amc3330.pdf
C1 | 1uF |  | EWS:C1 | ; 0805, >=25V; C0G for 100pF/1nF, X7R otherwise; verify effective capacitance | HOLD: select manufacturer part against value, footprint and ratings
C2 | 1nF |  | EWS:C2 | ; 0805, >=25V; C0G for 100pF/1nF, X7R otherwise; verify effective capacitance | HOLD: select manufacturer part against value, footprint and ratings
C3 | 100nF |  | EWS:C3 | ; 0805, >=25V; C0G for 100pF/1nF, X7R otherwise; verify effective capacitance | HOLD: select manufacturer part against value, footprint and ratings
C4 | 1nF |  | EWS:C4 | ; 0805, >=25V; C0G for 100pF/1nF, X7R otherwise; verify effective capacitance | HOLD: select manufacturer part against value, footprint and ratings
C5 | 100nF |  | EWS:C5 | ; 0805, >=25V; C0G for 100pF/1nF, X7R otherwise; verify effective capacitance | HOLD: select manufacturer part against value, footprint and ratings
C6 | 1nF |  | EWS:C6 | ; 0805, >=25V; C0G for 100pF/1nF, X7R otherwise; verify effective capacitance | HOLD: select manufacturer part against value, footprint and ratings
C7 | 1uF |  | EWS:C7 | ; 0805, >=25V; C0G for 100pF/1nF, X7R otherwise; verify effective capacitance | HOLD: select manufacturer part against value, footprint and ratings
R1 | 1k 0.1% |  | EWS:R1 |  | HOLD: select manufacturer part against value, footprint and ratings
R2 | 1k 0.1% |  | EWS:R2 |  | HOLD: select manufacturer part against value, footprint and ratings
C8 | 100pF C0G |  | EWS:C8 | ; 0805, >=25V; C0G for 100pF/1nF, X7R otherwise; verify effective capacitance | HOLD: select manufacturer part against value, footprint and ratings
R3 | 47k |  | EWS:R3 |  | HOLD: select manufacturer part against value, footprint and ratings
R100 | 249k 0.1% 200V | TNPW1206249KBEEA | EWS:R100 |  | Selected candidate; verify exact supplier drawing and availability | https://www.vishay.com/docs/28758/tnpw_e3.pdf
R101 | 249k 0.1% 200V | TNPW1206249KBEEA | EWS:R101 |  | Selected candidate; verify exact supplier drawing and availability | https://www.vishay.com/docs/28758/tnpw_e3.pdf
R102 | 249k 0.1% 200V | TNPW1206249KBEEA | EWS:R102 |  | Selected candidate; verify exact supplier drawing and availability | https://www.vishay.com/docs/28758/tnpw_e3.pdf
R103 | 249k 0.1% 200V | TNPW1206249KBEEA | EWS:R103 |  | Selected candidate; verify exact supplier drawing and availability | https://www.vishay.com/docs/28758/tnpw_e3.pdf
R104 | 249k 0.1% 200V | TNPW1206249KBEEA | EWS:R104 |  | Selected candidate; verify exact supplier drawing and availability | https://www.vishay.com/docs/28758/tnpw_e3.pdf
R105 | 249k 0.1% 200V | TNPW1206249KBEEA | EWS:R105 |  | Selected candidate; verify exact supplier drawing and availability | https://www.vishay.com/docs/28758/tnpw_e3.pdf
R106 | 249k 0.1% 200V | TNPW1206249KBEEA | EWS:R106 |  | Selected candidate; verify exact supplier drawing and availability | https://www.vishay.com/docs/28758/tnpw_e3.pdf
R107 | 249k 0.1% 200V | TNPW1206249KBEEA | EWS:R107 |  | Selected candidate; verify exact supplier drawing and availability | https://www.vishay.com/docs/28758/tnpw_e3.pdf
D1 | BAV199 | BAV199,215 | EWS:D1 |  | Selected candidate; verify exact supplier drawing and availability | https://assets.nexperia.com/documents/data-sheet/BAV199.pdf
D2 | BAV199 | BAV199,215 | EWS:D2 |  | Selected candidate; verify exact supplier drawing and availability | https://assets.nexperia.com/documents/data-sheet/BAV199.pdf
U3 | AMC3330DWER | AMC3330DWER | EWS:U3 |  | Selected candidate; verify exact supplier drawing and availability | https://www.ti.com/lit/ds/symlink/amc3330.pdf
C11 | 1uF |  | EWS:C11 | ; 0805, >=25V; C0G for 100pF/1nF, X7R otherwise; verify effective capacitance | HOLD: select manufacturer part against value, footprint and ratings
C12 | 1nF |  | EWS:C12 | ; 0805, >=25V; C0G for 100pF/1nF, X7R otherwise; verify effective capacitance | HOLD: select manufacturer part against value, footprint and ratings
C13 | 100nF |  | EWS:C13 | ; 0805, >=25V; C0G for 100pF/1nF, X7R otherwise; verify effective capacitance | HOLD: select manufacturer part against value, footprint and ratings
C14 | 1nF |  | EWS:C14 | ; 0805, >=25V; C0G for 100pF/1nF, X7R otherwise; verify effective capacitance | HOLD: select manufacturer part against value, footprint and ratings
C15 | 100nF |  | EWS:C15 | ; 0805, >=25V; C0G for 100pF/1nF, X7R otherwise; verify effective capacitance | HOLD: select manufacturer part against value, footprint and ratings
C16 | 1nF |  | EWS:C16 | ; 0805, >=25V; C0G for 100pF/1nF, X7R otherwise; verify effective capacitance | HOLD: select manufacturer part against value, footprint and ratings
C17 | 1uF |  | EWS:C17 | ; 0805, >=25V; C0G for 100pF/1nF, X7R otherwise; verify effective capacitance | HOLD: select manufacturer part against value, footprint and ratings
R11 | 100k 0.1% |  | EWS:R11 |  | HOLD: select manufacturer part against value, footprint and ratings
R12 | 100k 0.1% |  | EWS:R12 |  | HOLD: select manufacturer part against value, footprint and ratings
C18 | 100pF C0G |  | EWS:C18 | ; 0805, >=25V; C0G for 100pF/1nF, X7R otherwise; verify effective capacitance | HOLD: select manufacturer part against value, footprint and ratings
R13 | 47k |  | EWS:R13 |  | HOLD: select manufacturer part against value, footprint and ratings
R110 | 249k 0.1% 200V | TNPW1206249KBEEA | EWS:R110 |  | Selected candidate; verify exact supplier drawing and availability | https://www.vishay.com/docs/28758/tnpw_e3.pdf
R111 | 249k 0.1% 200V | TNPW1206249KBEEA | EWS:R111 |  | Selected candidate; verify exact supplier drawing and availability | https://www.vishay.com/docs/28758/tnpw_e3.pdf
R112 | 249k 0.1% 200V | TNPW1206249KBEEA | EWS:R112 |  | Selected candidate; verify exact supplier drawing and availability | https://www.vishay.com/docs/28758/tnpw_e3.pdf
R113 | 249k 0.1% 200V | TNPW1206249KBEEA | EWS:R113 |  | Selected candidate; verify exact supplier drawing and availability | https://www.vishay.com/docs/28758/tnpw_e3.pdf
R114 | 249k 0.1% 200V | TNPW1206249KBEEA | EWS:R114 |  | Selected candidate; verify exact supplier drawing and availability | https://www.vishay.com/docs/28758/tnpw_e3.pdf
R115 | 249k 0.1% 200V | TNPW1206249KBEEA | EWS:R115 |  | Selected candidate; verify exact supplier drawing and availability | https://www.vishay.com/docs/28758/tnpw_e3.pdf
R116 | 249k 0.1% 200V | TNPW1206249KBEEA | EWS:R116 |  | Selected candidate; verify exact supplier drawing and availability | https://www.vishay.com/docs/28758/tnpw_e3.pdf
R117 | 249k 0.1% 200V | TNPW1206249KBEEA | EWS:R117 |  | Selected candidate; verify exact supplier drawing and availability | https://www.vishay.com/docs/28758/tnpw_e3.pdf
D3 | BAV199 | BAV199,215 | EWS:D3 |  | Selected candidate; verify exact supplier drawing and availability | https://assets.nexperia.com/documents/data-sheet/BAV199.pdf
D4 | BAV199 | BAV199,215 | EWS:D4 |  | Selected candidate; verify exact supplier drawing and availability | https://assets.nexperia.com/documents/data-sheet/BAV199.pdf
U4 | ADS1115IDGSR | ADS1115IDGSR | EWS:U4 | 0x48: continuous HI AIN0-AIN1; 860 SPS nominal | Selected candidate; verify exact supplier drawing and availability | https://www.ti.com/lit/ds/symlink/ads1115.pdf
C30 | 100nF |  | EWS:C30 | ; 0805, >=25V; C0G for 100pF/1nF, X7R otherwise; verify effective capacitance | HOLD: select manufacturer part against value, footprint and ratings
R30 | 1k |  | EWS:R30 |  | HOLD: select manufacturer part against value, footprint and ratings
R31 | 1k |  | EWS:R31 |  | HOLD: select manufacturer part against value, footprint and ratings
C31 | 330nF |  | EWS:C31 | ; 0805, >=25V; C0G for 100pF/1nF, X7R otherwise; verify effective capacitance | HOLD: select manufacturer part against value, footprint and ratings
R32 | 1k |  | EWS:R32 |  | HOLD: select manufacturer part against value, footprint and ratings
R33 | 1k |  | EWS:R33 |  | HOLD: select manufacturer part against value, footprint and ratings
C32 | 330nF |  | EWS:C32 | ; 0805, >=25V; C0G for 100pF/1nF, X7R otherwise; verify effective capacitance | HOLD: select manufacturer part against value, footprint and ratings
R40 | 4.7k |  | EWS:R40 |  | HOLD: select manufacturer part against value, footprint and ratings
R41 | 4.7k |  | EWS:R41 |  | HOLD: select manufacturer part against value, footprint and ratings
R42 | 10k |  | EWS:R42 |  | HOLD: select manufacturer part against value, footprint and ratings
J4 | ADC_DIAGNOSTICS |  | EWS:J4 |  | HOLD: select manufacturer part against value, footprint and ratings
J5 | PROBE_E2_G_5V_S |  | EWS:J5 |  | HOLD: select manufacturer part against value, footprint and ratings
J6 | PROBE_E4_G_5V_S |  | EWS:J6 |  | HOLD: select manufacturer part against value, footprint and ratings
J7 | STEER_G_5V_S |  | EWS:J7 |  | HOLD: select manufacturer part against value, footprint and ratings
J8 | ESC_G_NC_S |  | EWS:J8 |  | HOLD: select manufacturer part against value, footprint and ratings
R50 | 100k |  | EWS:R50 |  | HOLD: select manufacturer part against value, footprint and ratings
R51 | 100k |  | EWS:R51 |  | HOLD: select manufacturer part against value, footprint and ratings
R52 | 100k |  | EWS:R52 |  | HOLD: select manufacturer part against value, footprint and ratings
R53 | 100k |  | EWS:R53 |  | HOLD: select manufacturer part against value, footprint and ratings
U5 | Pololu_D24V10F5 | D24V10F5 (Pololu 2831) | EWS:U5 | Solder headers; module underside clearance >=2mm | Selected candidate; verify exact supplier drawing and availability | https://www.pololu.com/product/2831
U6 | Pololu_D24V50F5 | D24V50F5 (Pololu 2851) | EWS:U6 | Solder headers; module underside clearance >=2mm | Selected candidate; verify exact supplier drawing and availability | https://www.pololu.com/product/2851
J9 | REG_CTRL_VIN_REFERENCED |  | EWS:J9 |  | HOLD: select manufacturer part against value, footprint and ratings
J10 | POWER_AUX |  | EWS:J10 |  | HOLD: select manufacturer part against value, footprint and ratings
J11 | 2S_INPUT_EXTERNAL_FUSE |  | EWS:J11 |  | HOLD: select manufacturer part against value, footprint and ratings
J12 | ELECTRODE_E2 |  | EWS:J12 |  | HOLD: select manufacturer part against value, footprint and ratings
J13 | ELECTRODE_E4 |  | EWS:J13 |  | HOLD: select manufacturer part against value, footprint and ratings
U7 | ADS1115IDGSR | ADS1115IDGSR | EWS:U7 | 0x49: continuous LO AIN0-AIN1; independent clock, not phase synchronous | Selected candidate; verify exact supplier drawing and availability | https://www.ti.com/lit/ds/symlink/ads1115.pdf
C33 | 100nF 25V X7R | GRM21BR71E104KA01L | EWS:C33 |  | Selected candidate; verify exact supplier drawing and availability
R43 | 10k 1% | RC0805FR-0710KL | EWS:R43 |  | Selected candidate; verify exact supplier drawing and availability
F1 | 3A fast fuse | 0453003.MR | EWS:F1 | Prototype 3A; coordinate with harness fuse, inrush and measured load; referenced KiCad 3D file absent locally: Fusion uses labelled provisional clearance envelope, verify supplier dimensions | Selected candidate; verify exact supplier drawing and availability | https://www.littelfuse.com/~/media/electronics/datasheets/fuses/littelfuse_fuse_451_453_datasheet.pdf.pdf
Q1 | DMPH3010LK3-13 | DMPH3010LK3-13 | EWS:Q1 | Reverse input protection: pin2/tab drain=fused input; pin3 source=VBAT | Selected candidate; verify exact supplier drawing and availability | https://www.diodes.com/datasheet/download/DMPH3010LK3.pdf
R60 | 100k 1% | RC0805FR-07100KL | EWS:R60 |  | Selected candidate; verify exact supplier drawing and availability
D5 | SMBJ12A | SMBJ12A | EWS:D5 | 12V standoff; 19.9V specified clamp; downstream of F1/Q1 | Selected candidate; verify exact supplier drawing and availability | https://m.littelfuse.com/~/media/electronics/datasheets/tvs_diodes/littelfuse_tvs_diode_smbj_datasheet.pdf.pdf
D6 | BZT52H-C10 | BZT52H-C10,115 | EWS:D6 | 10V gate-source clamp, cathode at source | Selected candidate; verify exact supplier drawing and availability | https://assets.nexperia.com/documents/data-sheet/BZT52H_SER.pdf
C40 | 10uF 25V X5R | GRM21BR61E106KA73L | EWS:C40 | Under U6; <=1.35mm body, >=2mm module standoff; verify DC-bias curve and actual module gap | Selected candidate; verify exact supplier drawing and availability | https://www.ti.com/mx/lit/pdf/sbau413
C41 | 10uF 25V X5R | GRM21BR61E106KA73L | EWS:C41 | Under U5; <=1.35mm body, >=2mm module standoff; verify DC-bias curve and actual module gap | Selected candidate; verify exact supplier drawing and availability | https://www.ti.com/mx/lit/pdf/sbau413
C42 | 10uF 25V X5R | GRM21BR61E106KA73L | EWS:C42 | Under U6; <=1.35mm body, >=2mm module standoff; verify DC-bias curve and actual module gap | Selected candidate; verify exact supplier drawing and availability | https://www.ti.com/mx/lit/pdf/sbau413
R61 | 200k 0.1% | TNPW0805200KBEEA | EWS:R61 | Under socketed DevKitC; verify at least 2mm underside clearance | Selected candidate; verify exact supplier drawing and availability | https://www.vishay.com/docs/28758/tnpw_e3.pdf
R62 | 33k 0.1% | TNPW080533K0BEEA | EWS:R62 | Under socketed DevKitC; verify at least 2mm underside clearance | Selected candidate; verify exact supplier drawing and availability | https://www.vishay.com/docs/28758/tnpw_e3.pdf
R63 | 10k 1% | RC0805FR-0710KL | EWS:R63 | Under socketed DevKitC; verify at least 2mm underside clearance | Selected candidate; verify exact supplier drawing and availability
C43 | 100nF 25V X7R | GRM21BR71E104KA01L | EWS:C43 | Under socketed DevKitC; verify at least 2mm underside clearance | Selected candidate; verify exact supplier drawing and availability
J14 | DRY_LEAK_SENSOR | TSW-103-07-G-S | EWS:J14 | Dry interior 3.3V open-drain sensor; not an electrode/conductivity port; generic 3-pin CAD envelope, verify selected TSW lead lengths and mating plug access | Selected candidate; verify exact supplier drawing and availability
R64 | 1k 1% | RC0805FR-071KL | EWS:R64 | Under socketed DevKitC; verify at least 2mm underside clearance | Selected candidate; verify exact supplier drawing and availability
R65 | 10k 1% | RC0805FR-0710KL | EWS:R65 | Under socketed DevKitC; verify at least 2mm underside clearance | Selected candidate; verify exact supplier drawing and availability
C44 | 100nF 25V X7R | GRM21BR71E104KA01L | EWS:C44 | Under socketed DevKitC; verify at least 2mm underside clearance | Selected candidate; verify exact supplier drawing and availability

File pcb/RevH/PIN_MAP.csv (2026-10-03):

connector | function | pin | net | note
J1 | EXPANSION_3V3_ONLY | 1 | 3V3
J1 | EXPANSION_3V3_ONLY | 2 | EN
J1 | EXPANSION_3V3_ONLY | 3 | ADC_READY | GPIO36: high ADC ready, reserved input
J1 | EXPANSION_3V3_ONLY | 4 | LO_DIAG | GPIO39: low amplifier diagnostic, reserved input
J1 | EXPANSION_3V3_ONLY | 5 | HI_DIAG | GPIO34: high amplifier diagnostic, reserved input
J1 | EXPANSION_3V3_ONLY | 6 | LO_READY | GPIO35: low ADC ready, reserved input
J1 | EXPANSION_3V3_ONLY | 7 | GPIO32 | Battery monitor ADC1 input; do not drive externally
J1 | EXPANSION_3V3_ONLY | 8 | GPIO33
J1 | EXPANSION_3V3_ONLY | 9 | GPIO25
J1 | EXPANSION_3V3_ONLY | 10 | GPIO26
J1 | EXPANSION_3V3_ONLY | 11 | GPIO27
J1 | EXPANSION_3V3_ONLY | 12 | GPIO14
J1 | EXPANSION_3V3_ONLY | 13 | GPIO12 | Boot strap: attached circuitry must preserve boot levels
J1 | EXPANSION_3V3_ONLY | 14 | GND
J1 | EXPANSION_3V3_ONLY | 15 | GPIO13
J1 | EXPANSION_3V3_ONLY | 16 | GPIO23 | Ingress sensor input; do not drive from expansion
J1 | EXPANSION_3V3_ONLY | 17 | GPIO22
J1 | EXPANSION_3V3_ONLY | 18 | GPIO1
J1 | EXPANSION_3V3_ONLY | 19 | GPIO3
J1 | EXPANSION_3V3_ONLY | 20 | GPIO21
J1 | EXPANSION_3V3_ONLY | 21 | GPIO19
J1 | EXPANSION_3V3_ONLY | 22 | GPIO18
J1 | EXPANSION_3V3_ONLY | 23 | GPIO5 | Boot strap: attached circuitry must preserve boot levels
J1 | EXPANSION_3V3_ONLY | 24 | GPIO17
J1 | EXPANSION_3V3_ONLY | 25 | GPIO16
J1 | EXPANSION_3V3_ONLY | 26 | GPIO4
J1 | EXPANSION_3V3_ONLY | 27 | GPIO0 | Boot strap: attached circuitry must preserve boot levels
J1 | EXPANSION_3V3_ONLY | 28 | GPIO2 | Boot strap: attached circuitry must preserve boot levels
J1 | EXPANSION_3V3_ONLY | 29 | GPIO15 | Boot strap: attached circuitry must preserve boot levels
J2 | I2C_3V3 | 1 | GND
J2 | I2C_3V3 | 2 | 3V3
J2 | I2C_3V3 | 3 | GPIO21
J2 | I2C_3V3 | 4 | GPIO22
J3 | UART_RESET | 1 | GND
J3 | UART_RESET | 2 | GPIO1
J3 | UART_RESET | 3 | GPIO3
J3 | UART_RESET | 4 | EN
JP1 | REMOVE_FOR_USB | 1 | LOGIC_5V
JP1 | REMOVE_FOR_USB | 2 | ESP_5V
J4 | ADC_DIAGNOSTICS | 1 | GND
J4 | ADC_DIAGNOSTICS | 2 | 3V3
J4 | ADC_DIAGNOSTICS | 3 | HI_DIAG | GPIO34: high amplifier diagnostic, reserved input
J4 | ADC_DIAGNOSTICS | 4 | LO_DIAG | GPIO39: low amplifier diagnostic, reserved input
J4 | ADC_DIAGNOSTICS | 5 | ADC_READY | GPIO36: high ADC ready, reserved input
J4 | ADC_DIAGNOSTICS | 6 | HI_ADC_P
J4 | ADC_DIAGNOSTICS | 7 | HI_ADC_N
J4 | ADC_DIAGNOSTICS | 8 | LO_ADC_P
J4 | ADC_DIAGNOSTICS | 9 | LO_ADC_N
J5 | PROBE_E2_G_5V_S | 1 | GND
J5 | PROBE_E2_G_5V_S | 2 | SERVO_5V
J5 | PROBE_E2_G_5V_S | 3 | GPIO25
J6 | PROBE_E4_G_5V_S | 1 | GND
J6 | PROBE_E4_G_5V_S | 2 | SERVO_5V
J6 | PROBE_E4_G_5V_S | 3 | GPIO26
J7 | STEER_G_5V_S | 1 | GND
J7 | STEER_G_5V_S | 2 | SERVO_5V
J7 | STEER_G_5V_S | 3 | GPIO27
J8 | ESC_G_NC_S | 1 | GND
J8 | ESC_G_NC_S | 2 | ESC_BEC_NC | Do not connect ESC BEC
J8 | ESC_G_NC_S | 3 | GPIO14
J9 | REG_CTRL_VIN_REFERENCED | 1 | REG_SHDN | VIN referenced: no direct GPIO connection
J9 | REG_CTRL_VIN_REFERENCED | 2 | REG_PG | VIN referenced: no direct GPIO connection
J9 | REG_CTRL_VIN_REFERENCED | 3 | SERVO_EN | VIN referenced: no direct GPIO connection
J9 | REG_CTRL_VIN_REFERENCED | 4 | GND
J10 | POWER_AUX | 1 | GND
J10 | POWER_AUX | 2 | 3V3
J10 | POWER_AUX | 3 | LOGIC_5V
J10 | POWER_AUX | 4 | GND
J11 | 2S_INPUT_EXTERNAL_FUSE | 1 | BAT_RAW | 2S battery, externally fused; 8.4V normal maximum
J11 | 2S_INPUT_EXTERNAL_FUSE | 2 | GND
J12 | ELECTRODE_E2 | 1 | E2 | Floating electrode input; insulation and strain relief required
J13 | ELECTRODE_E4 | 1 | E4 | Floating electrode input; insulation and strain relief required
J14 | DRY_LEAK_SENSOR | 1 | GND
J14 | DRY_LEAK_SENSOR | 2 | 3V3
J14 | DRY_LEAK_SENSOR | 3 | LEAK_EXT | Internal 3.3V open-drain sensor only; never an external water electrode

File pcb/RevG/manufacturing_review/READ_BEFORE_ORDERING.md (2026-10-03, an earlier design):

# Historical Rev G manufacturing candidates

These files belong to the previous prototype and are not current. Use [Rev H](../../RevH/README.md) for electronics development. Neither revision is a qualified energized-water instrument. Do not order these old exports as Rev H boards.

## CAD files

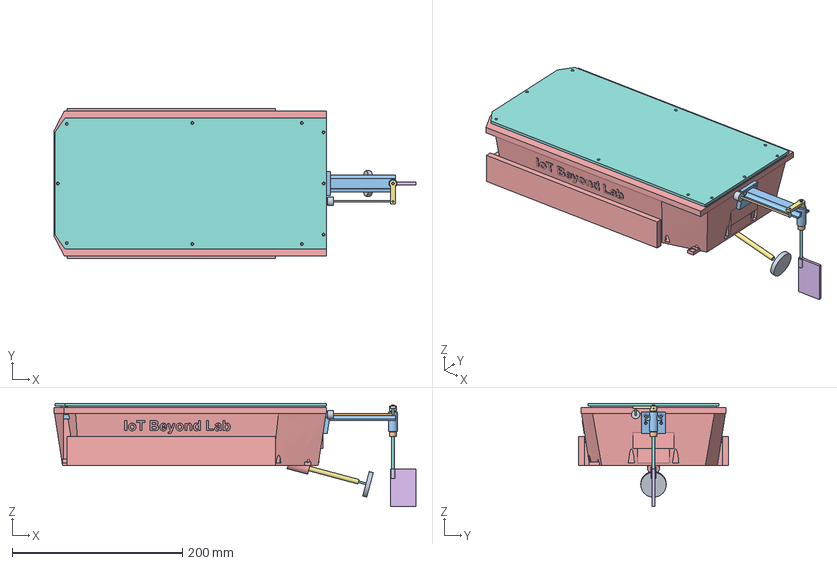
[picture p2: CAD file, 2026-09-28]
cad/Energized_Water_Scanner_RevE.step
425.0 x 176.0 x 121.0 mm

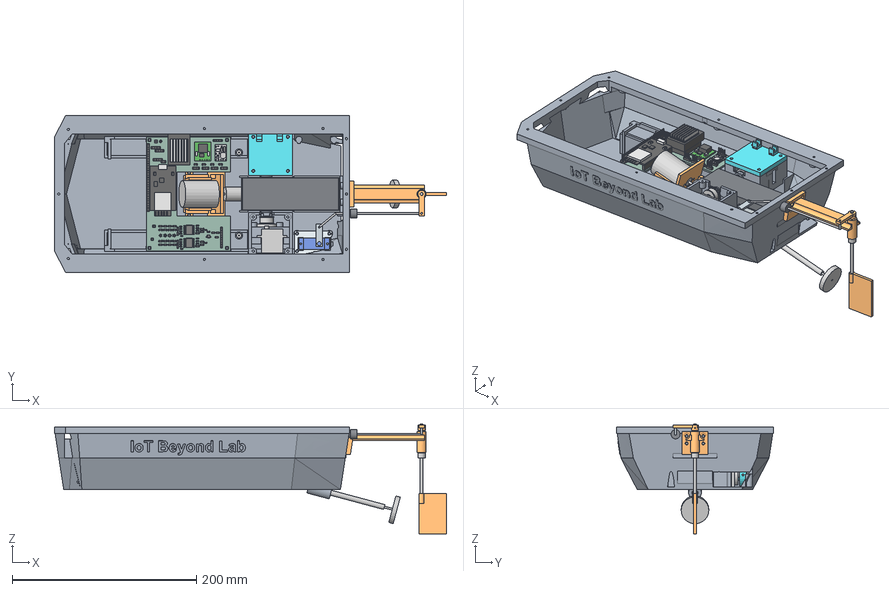
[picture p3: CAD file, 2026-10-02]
cad/RevG/Energized_Water_Scanner_RevG.step
425.0 x 170.0 x 119.0 mm
R_1206_3216Metric_1 x 33
C_0805_2012Metric_1 x 19
SOT-23-3_1 x 4
RevG_model_J6
RevG_model_J4
RevG_model_U5
RevG_model_J10
RevG_model_U1
MSOP-10_3x3mm_P0.5mm_1
RevG_model_J1
RevG_model_J9
RevG_model_J2
RevG_model_J8
RevG_model_J3
RevG_model_U6
RevG_model_J5
SOIC-16W_7.5x10.3mm_P1.27mm_1 x 2
RevG_model_JP1
RevG_model_J7
EWS_RevG_pad
EWS_RevG_PCB

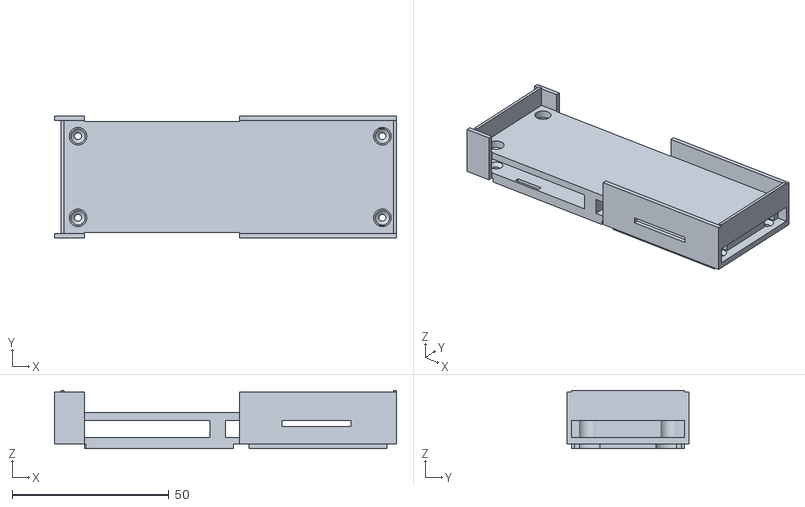
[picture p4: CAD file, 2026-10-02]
cad/RevG/stl/PRINT_04_Longitudinal_battery_cradle_1_Two_strap_battery_cradle_1_1_1_.stl
109.0 x 39.0 x 18.5

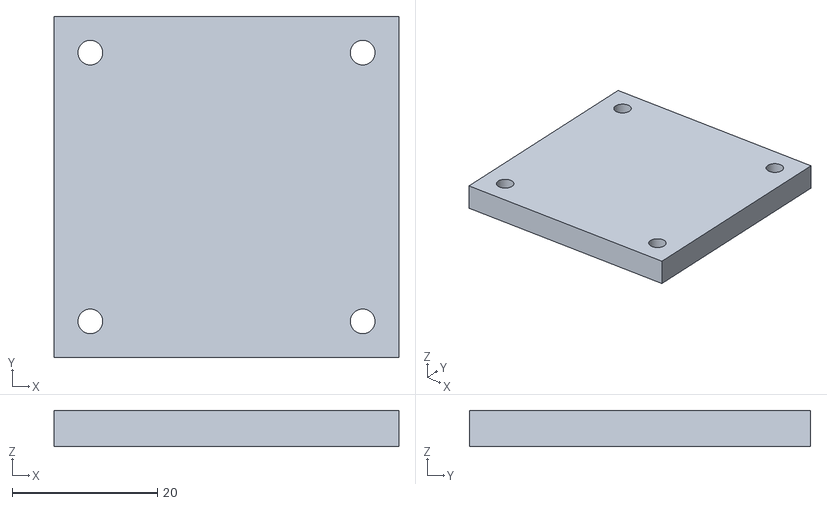
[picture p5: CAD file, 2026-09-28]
prints/PRINT_25_E4_internal_servo_cover.stl
47.5 x 47.0 x 5.00

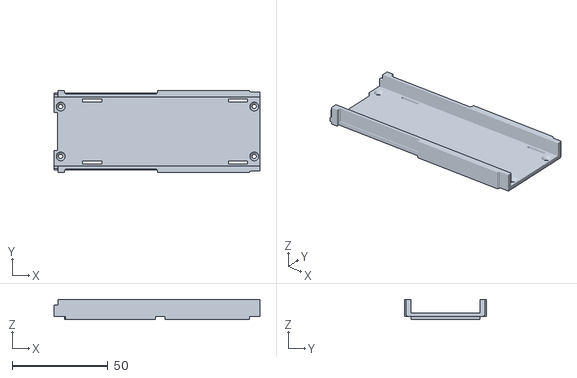
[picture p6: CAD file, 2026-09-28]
prints/PRINT_04_Longitudinal_battery_cradle.stl
107.5 x 43.0 x 10.5

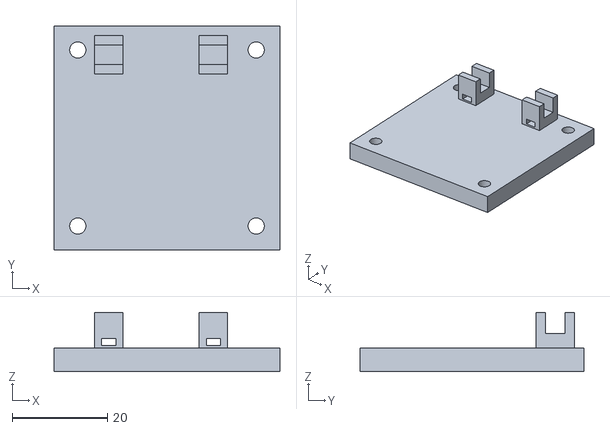
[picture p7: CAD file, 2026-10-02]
cad/RevG/stl/PRINT_25_E4_internal_servo_cover_1_Top_access_cover_wide_drive_bay_1_.stl
47.5 x 47.0 x 12.5

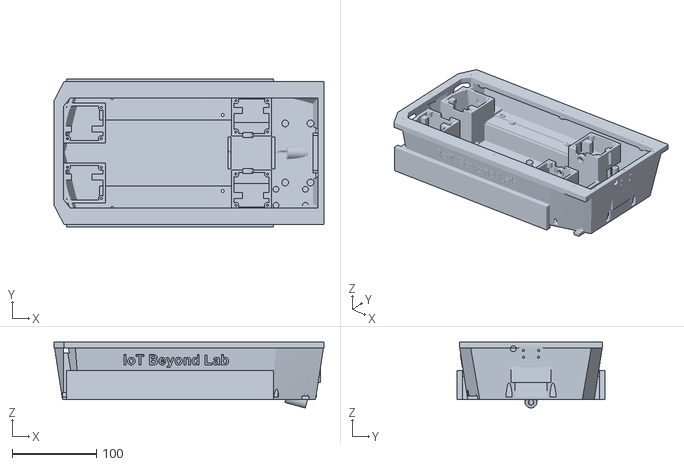
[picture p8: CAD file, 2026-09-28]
prints/PRINT_01_Hull_shell.stl
320.0 x 176.0 x 78.1

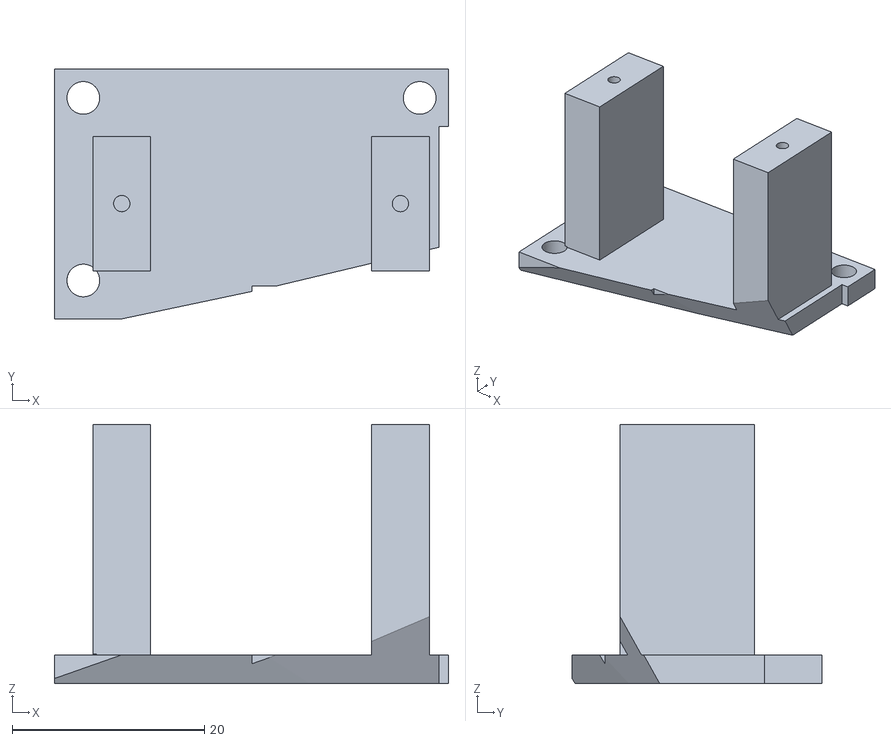
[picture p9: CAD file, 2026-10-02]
cad/RevG/stl/PRINT_30_Steering_service_saddle_1_RevF_Steering_saddle_chine_fit.stl
41.0 x 26.0 x 27.0

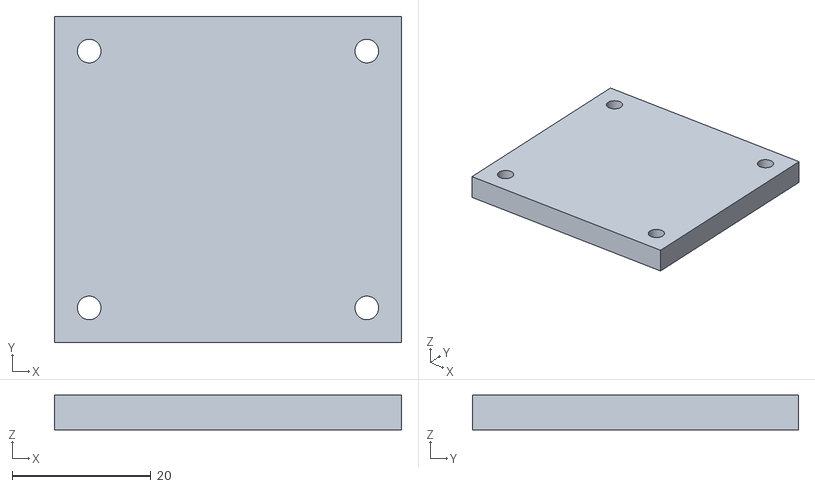
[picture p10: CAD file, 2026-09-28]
prints/PRINT_24_E3_internal_servo_cover.stl
50.0 x 47.0 x 5.00

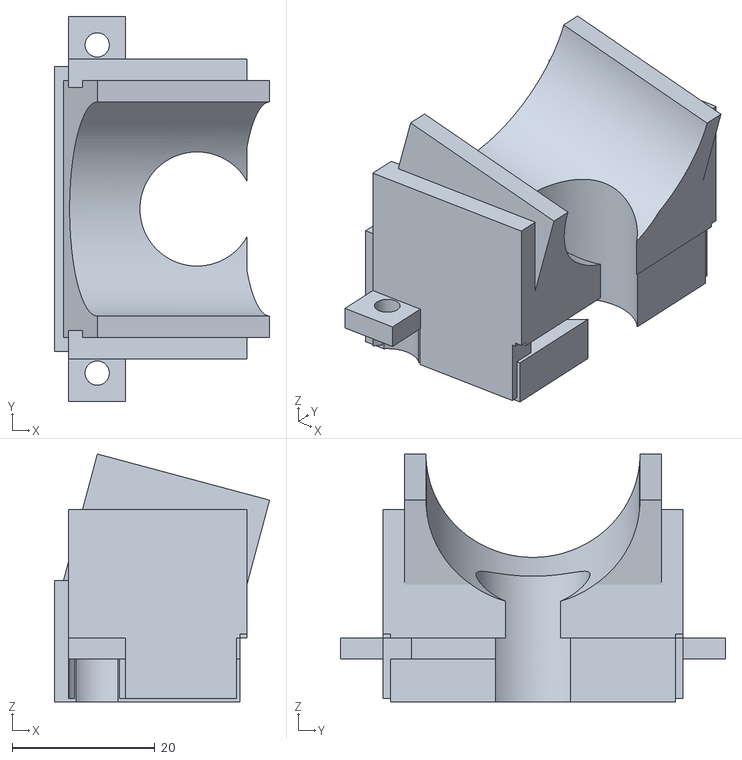
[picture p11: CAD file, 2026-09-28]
cad/RevG/stl/PRINT_14_Motor_lower_cradle_1_PRINT_14_Motor_lower_cradle.stl
30.2 x 54.0 x 34.8

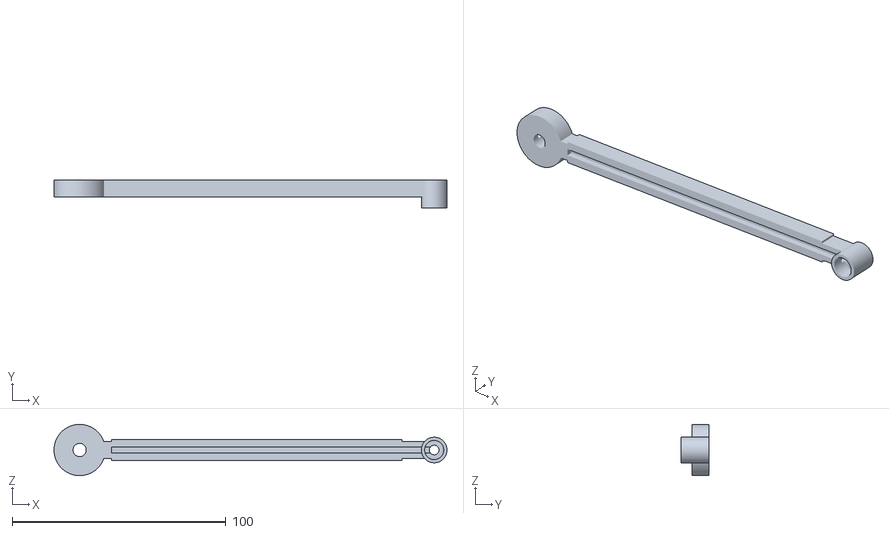
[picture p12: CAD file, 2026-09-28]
prints/PRINT_28_E3_insulated_arm.stl
184.0 x 13.0 x 24.0

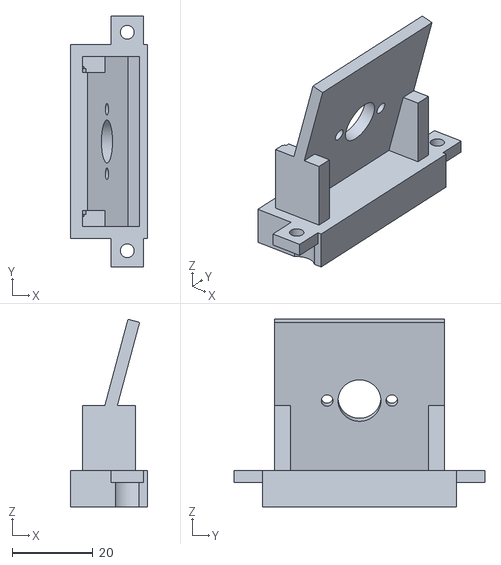
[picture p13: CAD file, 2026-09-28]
cad/RevG/stl/PRINT_11_Motor_face_mount_1_PRINT_11_Motor_face_mount.stl
19.0 x 62.0 x 46.3

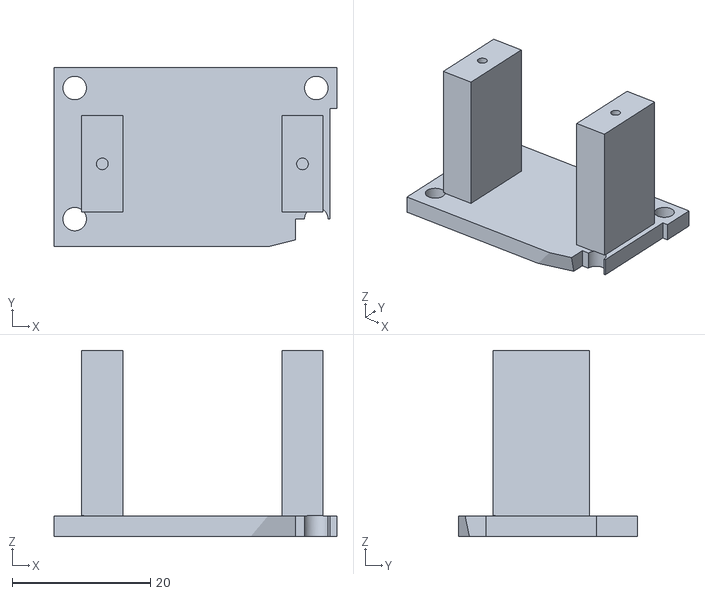
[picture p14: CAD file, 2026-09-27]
prints/PRINT_30_Steering_service_saddle.stl
41.0 x 26.0 x 27.0

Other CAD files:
cad/RevG/stl/PROBE_E2_MOVING_1_1_PRINT_27_E2_insulated_arm.stl
prints/PRINT_22_E1_internal_servo_cover.stl
cad/RevG/stl/PRINT_23_E2_internal_servo_cover_1_Top_access_cover_wide_drive_bay.stl
prints/PRINT_26_E1_insulated_arm.stl
cad/RevG/stl/PROBE_E4_MOVING_1_1_PRINT_29_E4_insulated_arm.stl
cad/Energized_Water_Scanner_RevE.f3d
cad/RevG/Energized_Water_Scanner_RevG.f3d
cad/RevG/stl/PRINT_01_Hull_shell_RevG_1_Hull_-_obsolete_controller_posts_removed.stl
cad/RevG/stl/PRINT_02_Removable_hatch_cover_1_1_Extended_service_hatch.stl
cad/RevG/stl/PRINT_09_Rudder_transom_bracket_1_Single_print_rudder_bracket.stl
cad/RevG/stl/PRINT_16_Rudder_blade_1_Rudder_blade_with_stock_socket.stl
cad/RevG/stl/PRINT_17_Rudder_tiller_1_Tiller_with_stock_socket.stl
pcb/RevG/EWS_RevG.step
pcb/RevG/models/H_spacer.step
pcb/RevG/models/J1.step
pcb/RevG/models/J10.step
pcb/RevG/models/J2.step
pcb/RevG/models/J3.step
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

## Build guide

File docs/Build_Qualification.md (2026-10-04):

# Remaining qualification work

Current status: Rev H electronics design, live Fusion Rev I mechanical assembly. See the [CAD audit](CAD_Audit_2026-10-04.md). No physical tests or certifications are implied by the CAD or automated electrical reports.

## Electronics and sensing

1. Independent schematic/pinout/protection review; verify supplier package drawings, BOM selections, six-layer stack and effective capacitor values. Establish applicable installation category, pollution degree, CTI, creepage, clearance and exposure envelope with a qualified laboratory.
2. Current-limited dry power-up: polarity protection, fuse coordination, regulated rails, USB isolation procedure, startup/brownout, servo stall and motor-noise coupling. Measure peak currents and trace/via/component temperatures.
3. Isolated low-energy calibration: DC polarity/offset, 50/60 Hz amplitude and phase response, range overlap, noise versus temperature, ADC rate variation, data-ready/DIAG faults, clipping and overload recovery. Test electrode lead open/short and dry/fouled probes; they must not produce a false safe indication.
4. Laboratory insulation, common-mode/differential exposure, transient, dielectric, leakage and single-fault tests. Include clamp/resistor faults, contamination/condensation, enclosure and lead insulation. A clean ERC/DRC or an amplifier isolation certificate does not rate the whole instrument.
5. Validate immersed-electrode polarization/loading, motion and conductivity effects separately. Set a measured sensitivity/bandwidth/uncertainty specification before implementing hazard thresholds. A single pair has directional blind spots.
6. Validate location/heading/pose and acquisition timestamps, stale-data rejection and fail-safe behavior. No operational acquisition or mapping firmware has been released for Rev H.

## Mechanical and water boundary

| Interface | Required work |
|---|---|
| Hull, chines and wet roofs | Verify print porosity/coating, support removal, material continuity and leak performance. |
| Hatch/gasket | Actual material, compression, flatness, fastener lengths and repeated-opening tests. |
| Two probe shafts/cartridges | Water-rated seals, shaft finish/tolerance, lubrication, axial retention and face-gasket compression. |
| Two electrode lead entries | Actual jacket/potting adhesion, void control, insulation, strain relief and full-motion flex life. |
| Propulsion tube/shaft | Outer bonded seal plus separate internal dynamic seal, lubrication, alignment and wear tests. |
| Steering boot and blind fasteners | Retention, travel/fatigue, real screw engagement and no breakthrough into wet spaces. |
| PCB and modules | Validate the Rev H populated Fusion fit on real hardware, 2 mm module standoffs, underside tails, nylon hardware, ESC retention, wiring and hatch clearance. |

Specify immersion head, duration, water type, temperature and actuation cycles. Test coupons/interfaces, then the empty assembled hull using dry witness material. Repeat after service cycles. Any ingress fails the tested condition. Internal probe covers are service covers, not independent watertight compartments.

Weigh the actual completed vessel. Measure displacement, freeboard, trim, stability and retrieval capability with the real pack, hardware and coatings. Test steering, propulsion, probe stops and jam response in controlled **unenergized** water. Nominal CAD mass or earlier hull dimensions cannot substitute for flotation tests.

Hazardous-voltage tests require an appropriately equipped laboratory. Do not use people, animals or occupied floodwater as test loads. A low or invalid reading never grants access to potentially energized water.

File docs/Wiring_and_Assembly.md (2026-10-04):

# Assembly and procurement

Use the [Rev H PCB BOM](../pcb/RevH/BOM.csv) for the carrier and the [system BOM](../BOM.csv) for remaining hardware. Do not buy a separate ADS1115 breakout or obsolete front-end module: the two converters and isolated front ends are on the PCB. The component BOM lists 95 populated references including the modules. Add the sockets, shunt and module standoffs listed in the PCB assembly BOM; its harness/PCB-fastener rows cross-reference the system BOM and must not be counted twice. Blank manufacturer selections are procurement holds, not approved substitutions.

The system BOM preserves unresolved supplier/interface warnings. It uses two probe mechanisms, three servos total, the retained battery/drivetrain, the Rev G 13-body print set, and revised PCB/ESC mounting hardware. Obtain and qualify one probe actuator before ordering its duplicate. Smooth timing-pulley envelopes do not define actual teeth, horn adaptation, tensioning or shaft retention. Verify the exact SG90 horn/lugs, motor mounting depth, coupling dimensions and propeller/shaft interfaces on supplier hardware.

1. Inspect the current hull, wet roofs, blind pilots and sealing lands. Qualify printing/coating on coupons. Do not deepen a blind pilot into a wet channel.
2. Resolve one E2/E4 actuator with matched pulleys/belt, actual servo horn, upper journal, shaft retention, cartridge, seal and bushing. Test travel, jam response, current and temperature before duplication.
3. Route E2/E4 leads with insulated hinge loops, strain relief and qualified potted entries. Keep them separated from motor/servo wiring. External wet conductors terminate only at the designated isolated electrode inputs.
4. Fit the propulsion and steering hardware. Qualify both the stern-tube outer bond and the internal rotating-shaft leakage path; one does not seal the other.
5. Install the Rev H carrier using the retained mounting pattern, 1 mm nylon spacers and verified screw engagement. Check trimmed solder tails. Fit the regulator modules with measured ≥2 mm underside clearance, including the added capacitors beneath them. Consult the Rev I CAD audit and verify the selected hardware and mating connectors physically.
6. Fit the external fused harness and the independently fused motor branch. Observe J11 polarity, fit F1/Q1 correctly, leave the ESC BEC lead insulated, and never parallel regulator outputs. Use a current-limited supply for initial power-up.
7. Fit two battery straps and qualified ESC retention. Retain the existing SJ3550 attachment concept pending bond/thermal tests. Keep wiring away from the hatch gasket and provide service slack.
8. If fitted, connect a compatible 3.3 V open-drain dry-compartment ingress sensor to J14 and test it before each run. J14 is not a wet-electrode or conductivity connector.

The [PCB pin map](../pcb/RevH/PIN_MAP.md) is authoritative. GPIO34/35/36/39, GPIO32 and GPIO23 now have onboard functions. Remove boat power and JP1 before USB service; lift the ESP32 from its sockets if necessary. Disconnect leads and ties before lifting the carrier or probe covers. The E4 cover's documented service path is 3 mm inward then upward, subject to confirmation on hardware.

The current mechanical reference is the live Fusion Rev I assembly; the named Rev G exports are historical. No new STL/STEP/F3D was produced. Use the active PRINT components in Fusion, excluding ARCHIVE and LIBRARY components; all printed parts remain subject to the [qualification plan](Build_Qualification.md).

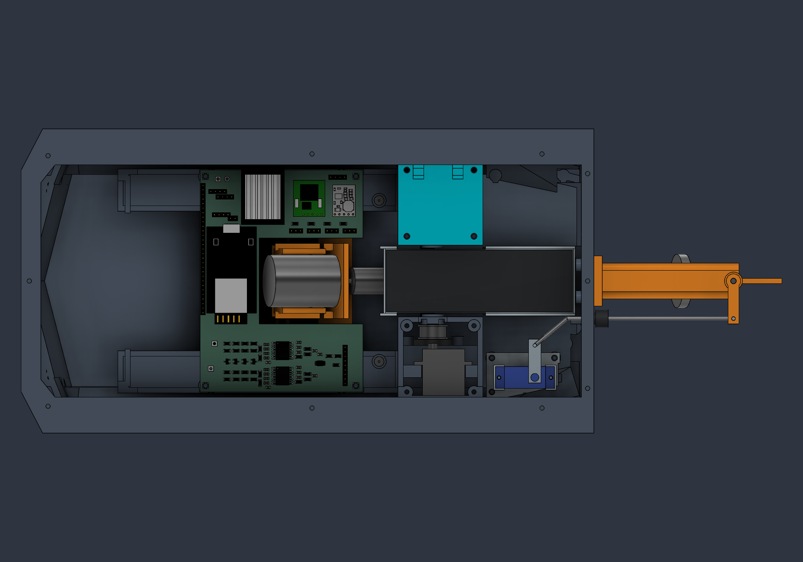
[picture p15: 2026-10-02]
previews/RevG_assembly_top.png

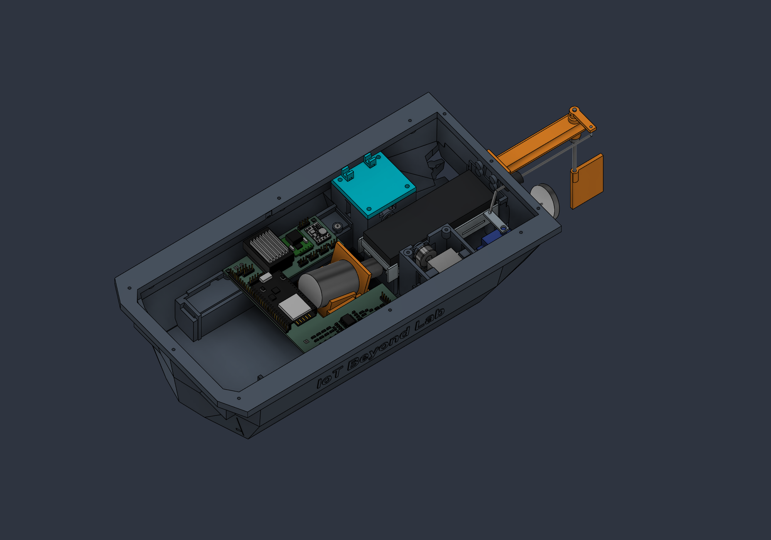
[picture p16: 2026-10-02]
cad/RevG/assembly_open.png

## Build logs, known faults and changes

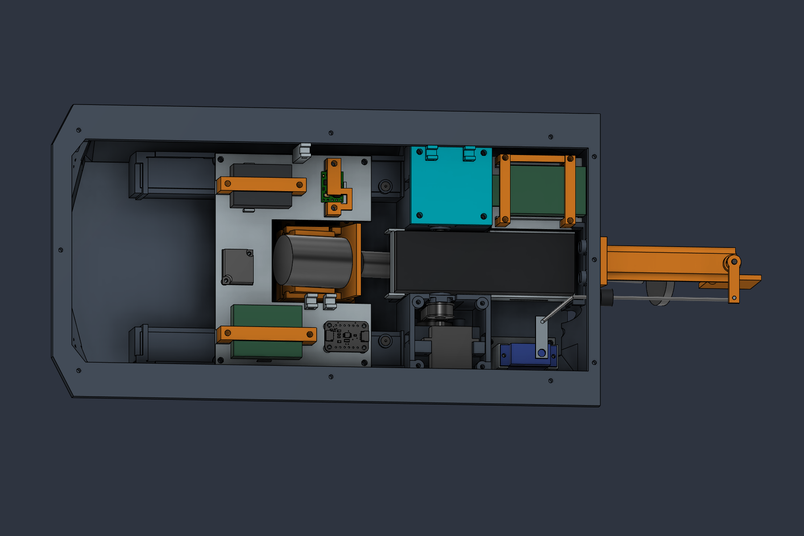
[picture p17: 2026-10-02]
pcb/engineering/live_fusion_before_changes.png

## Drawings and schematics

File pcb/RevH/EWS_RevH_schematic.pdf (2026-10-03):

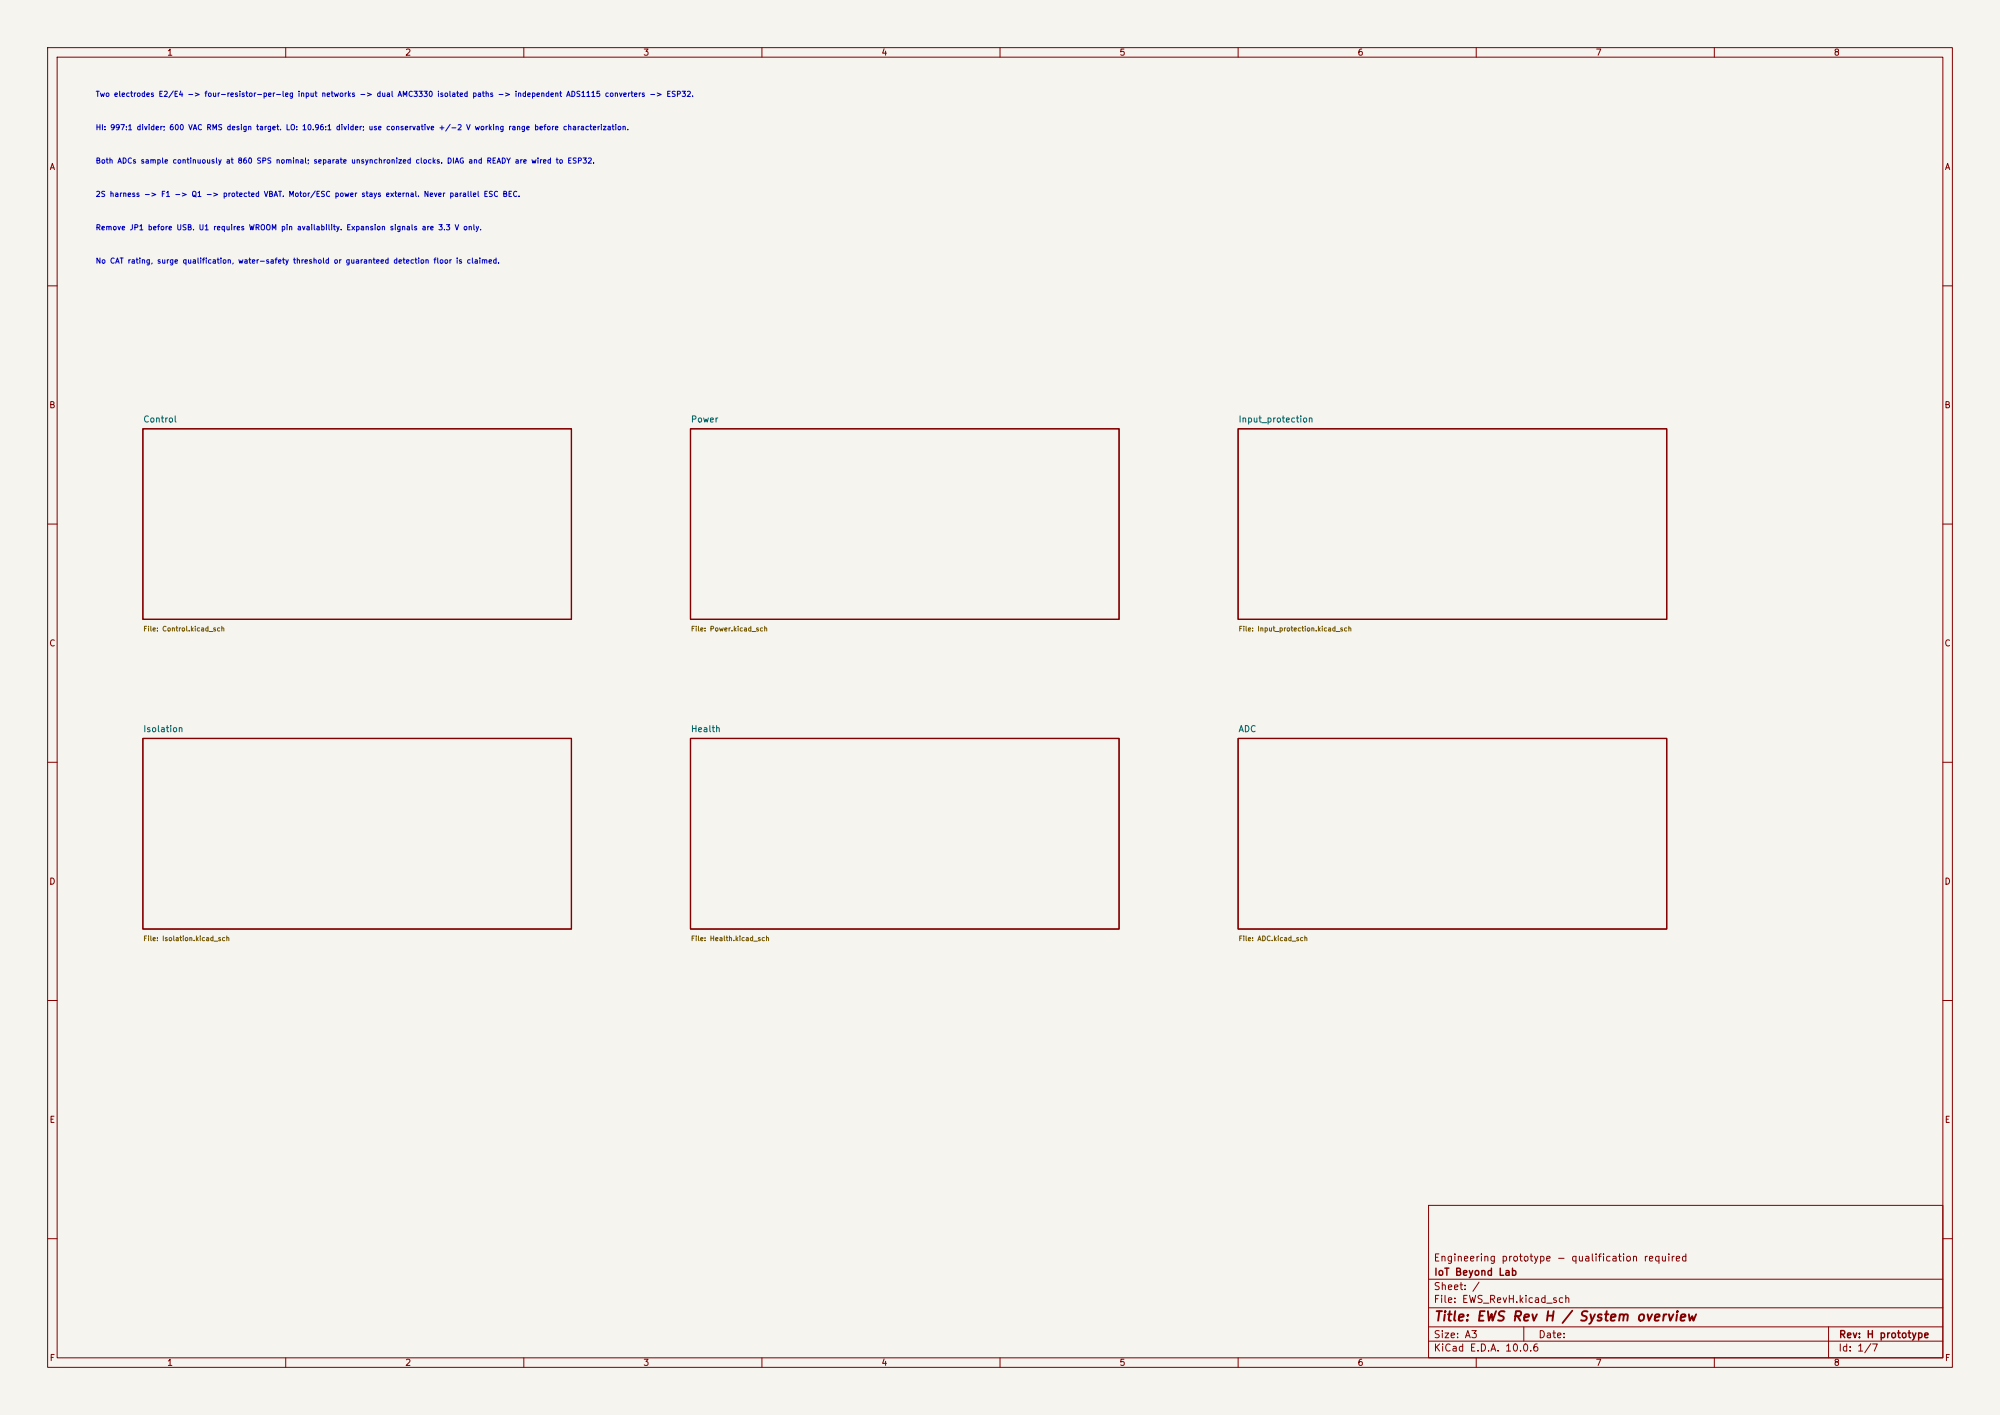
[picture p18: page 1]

Two electrodes E2/E4 -> four-resistor-per-leg input networks -> dual AMC3330 isolated paths -> independent ADS1115 converters -> ESP32. HI: 997:1 divider; 600 VAC RMS design target. LO: 10.96:1 divider; use conservative +/-2 V working range before characterization. Both ADCs sample continuously at 860 SPS nominal; separate unsynchronized clocks. DIAG and READY are wired to ESP32. 2S harness -> F1 -> Q1 -> protected VBAT. Motor/ESC power stays external. Never parallel ESC BEC. Remove JP1 before USB. U1 requires WROOM pin availability. Expansion signals are 3.3 V only. No CAT rating, surge qualification, water-safety threshold or guaranteed detection floor is claimed.

Engineering prototype - qualification required
IoT Beyond Lab
Sheet: /
File: EWS_RevH.kicad_sch
Title: EWS Rev H / System overview

Size: A3 | Rev: H prototype | F Date:
KiCad E.D.A. 10.0.6 | Id: 1/7

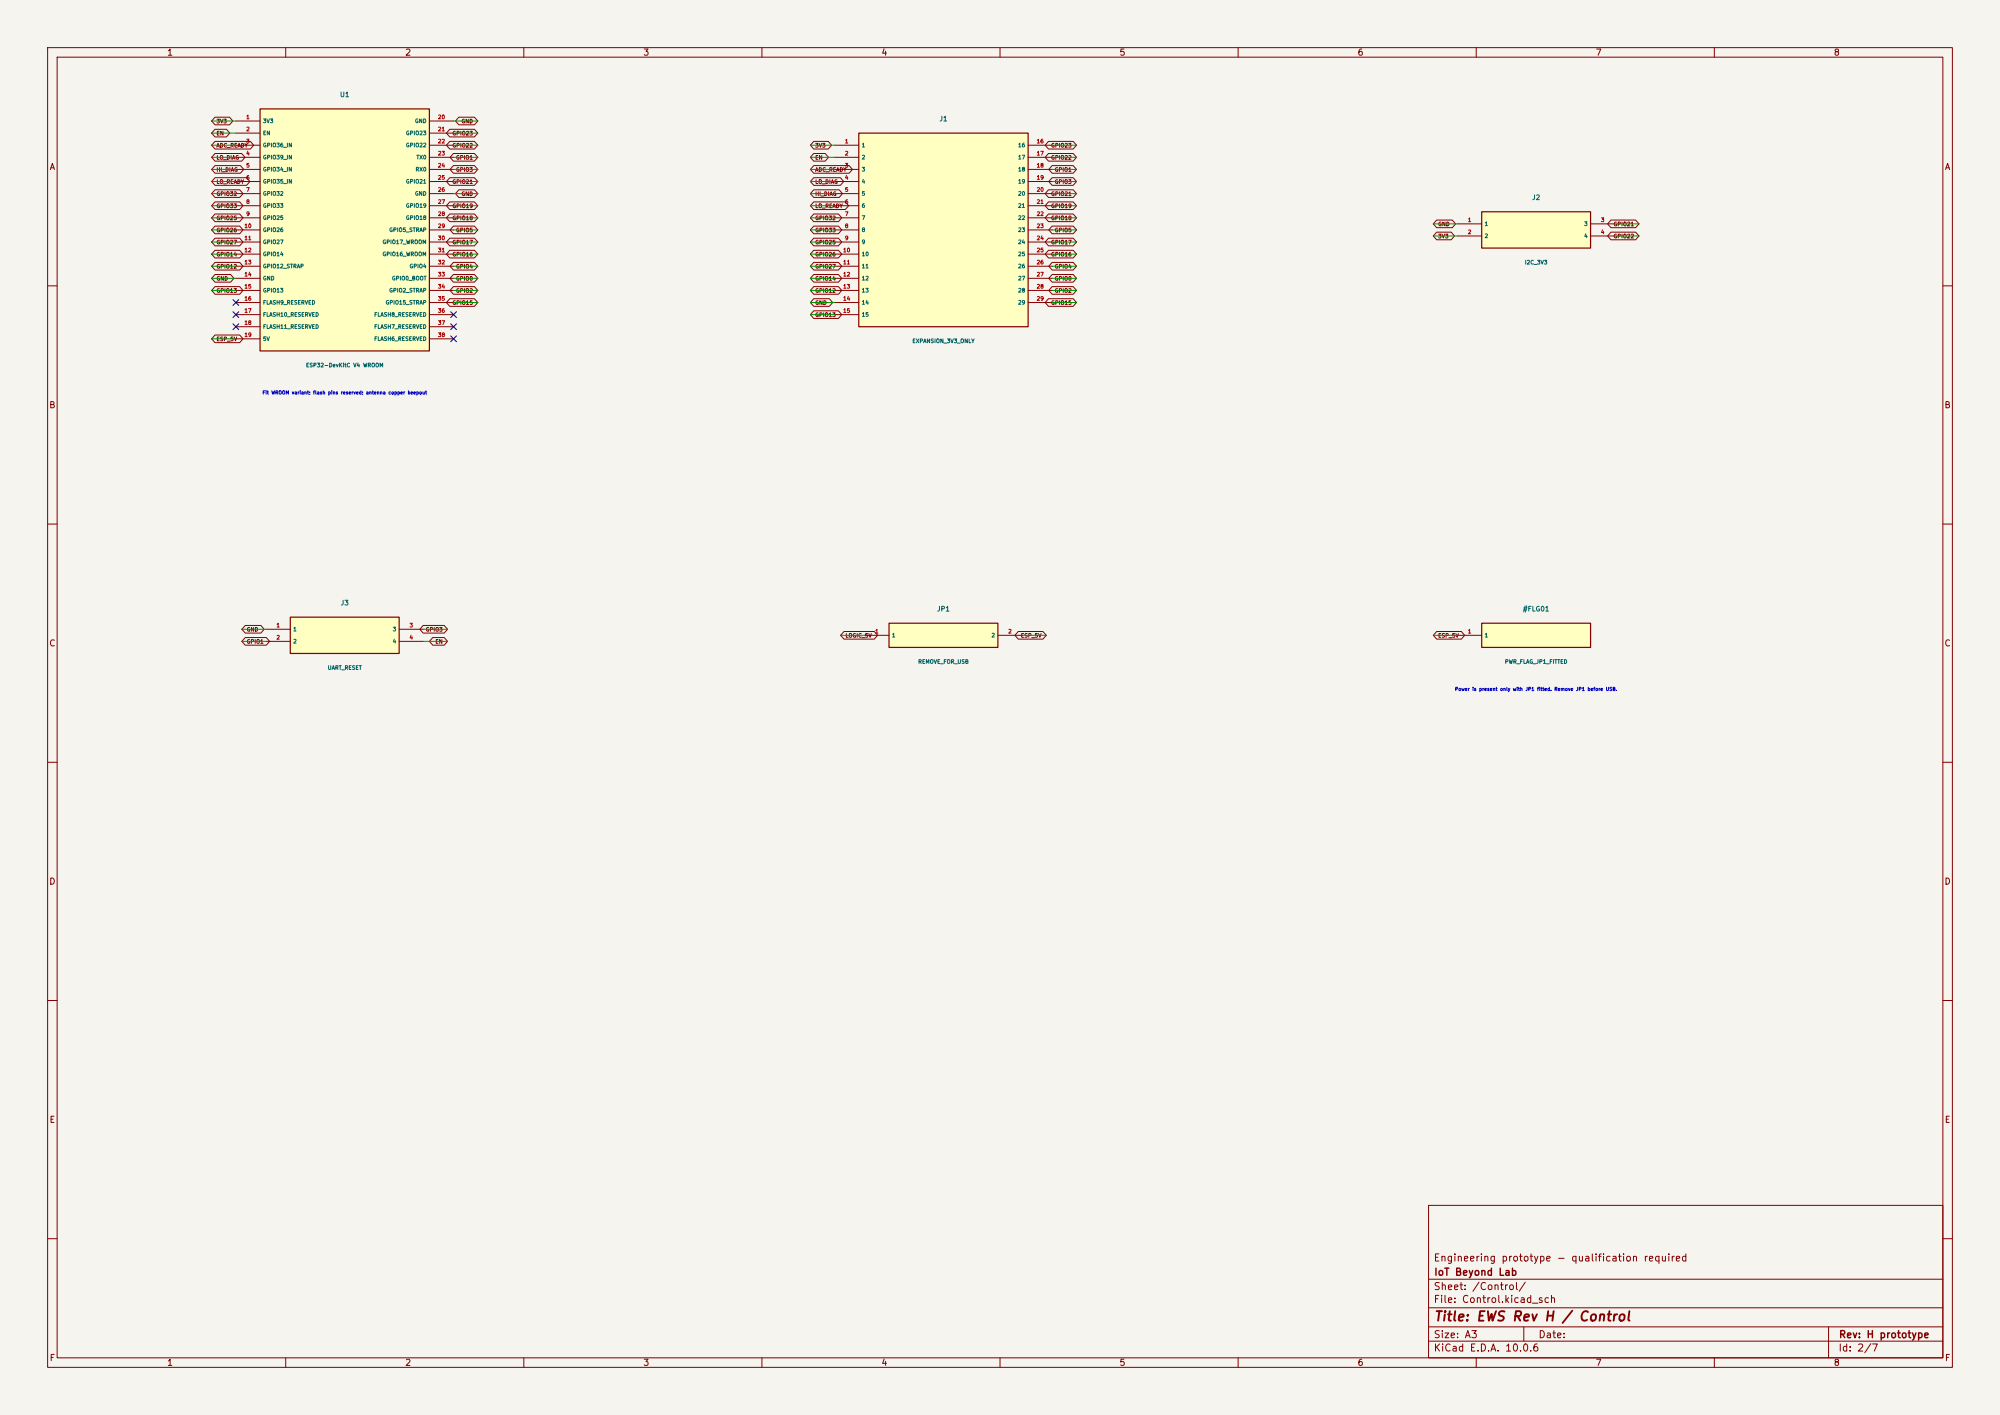
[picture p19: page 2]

Engineering prototype - qualification required
IoT Beyond Lab
Sheet: /Control/
File: Control.kicad_sch
Title: EWS Rev H / Control

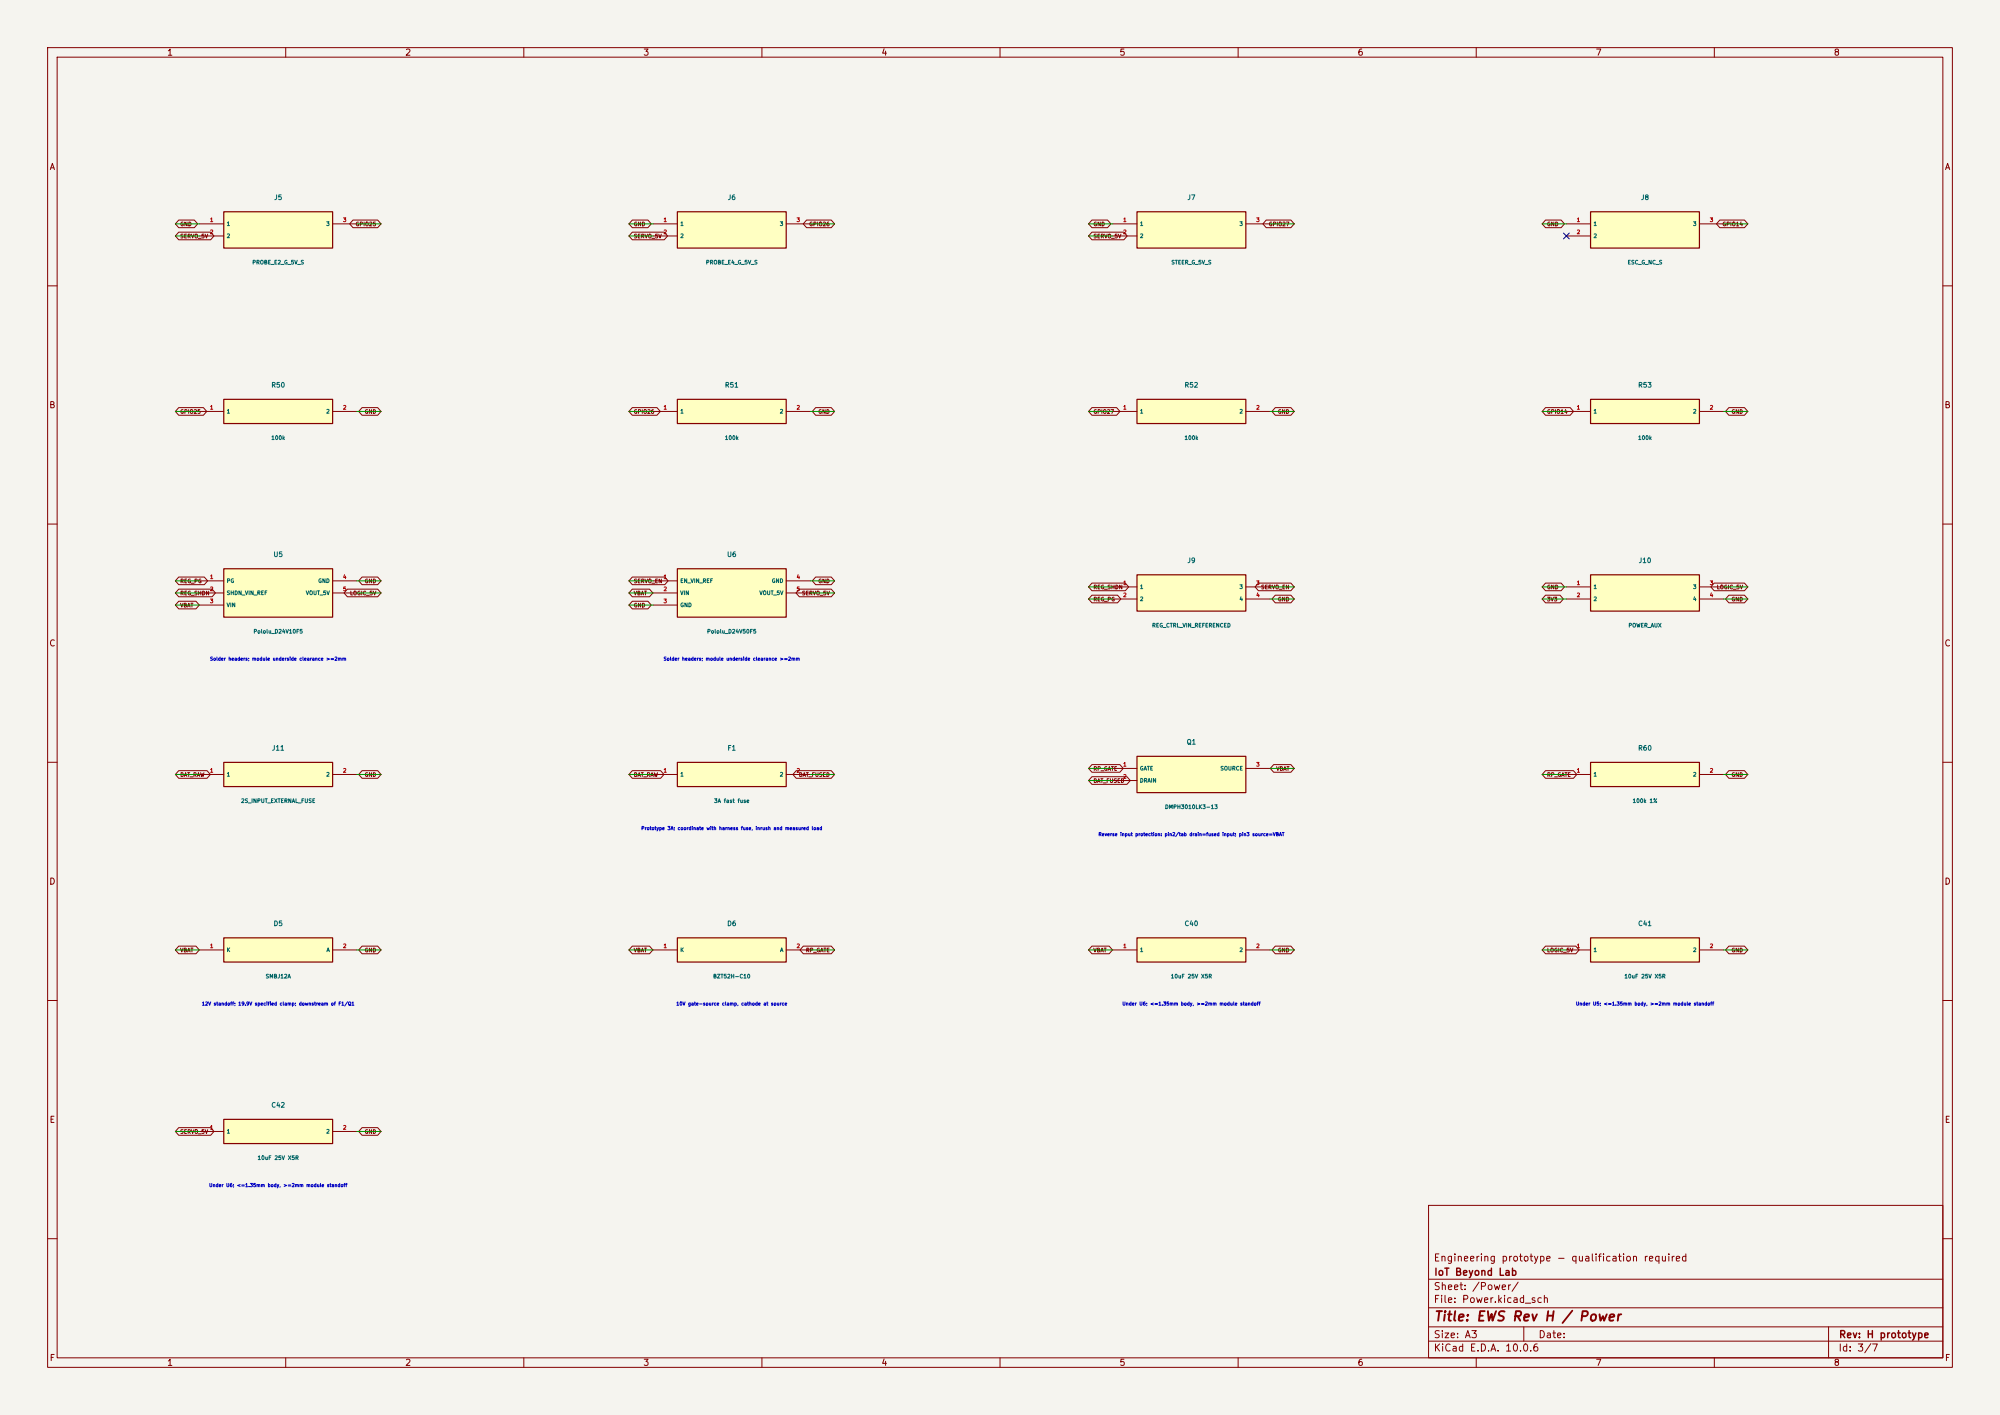
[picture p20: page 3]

Solder headers; module underside clearance >=2mm

Under U6; <=1.35mm body, >=2mm module standoff

Engineering prototype - qualification required
IoT Beyond Lab
Sheet: /Power/
File: Power.kicad_sch
Title: EWS Rev H / Power

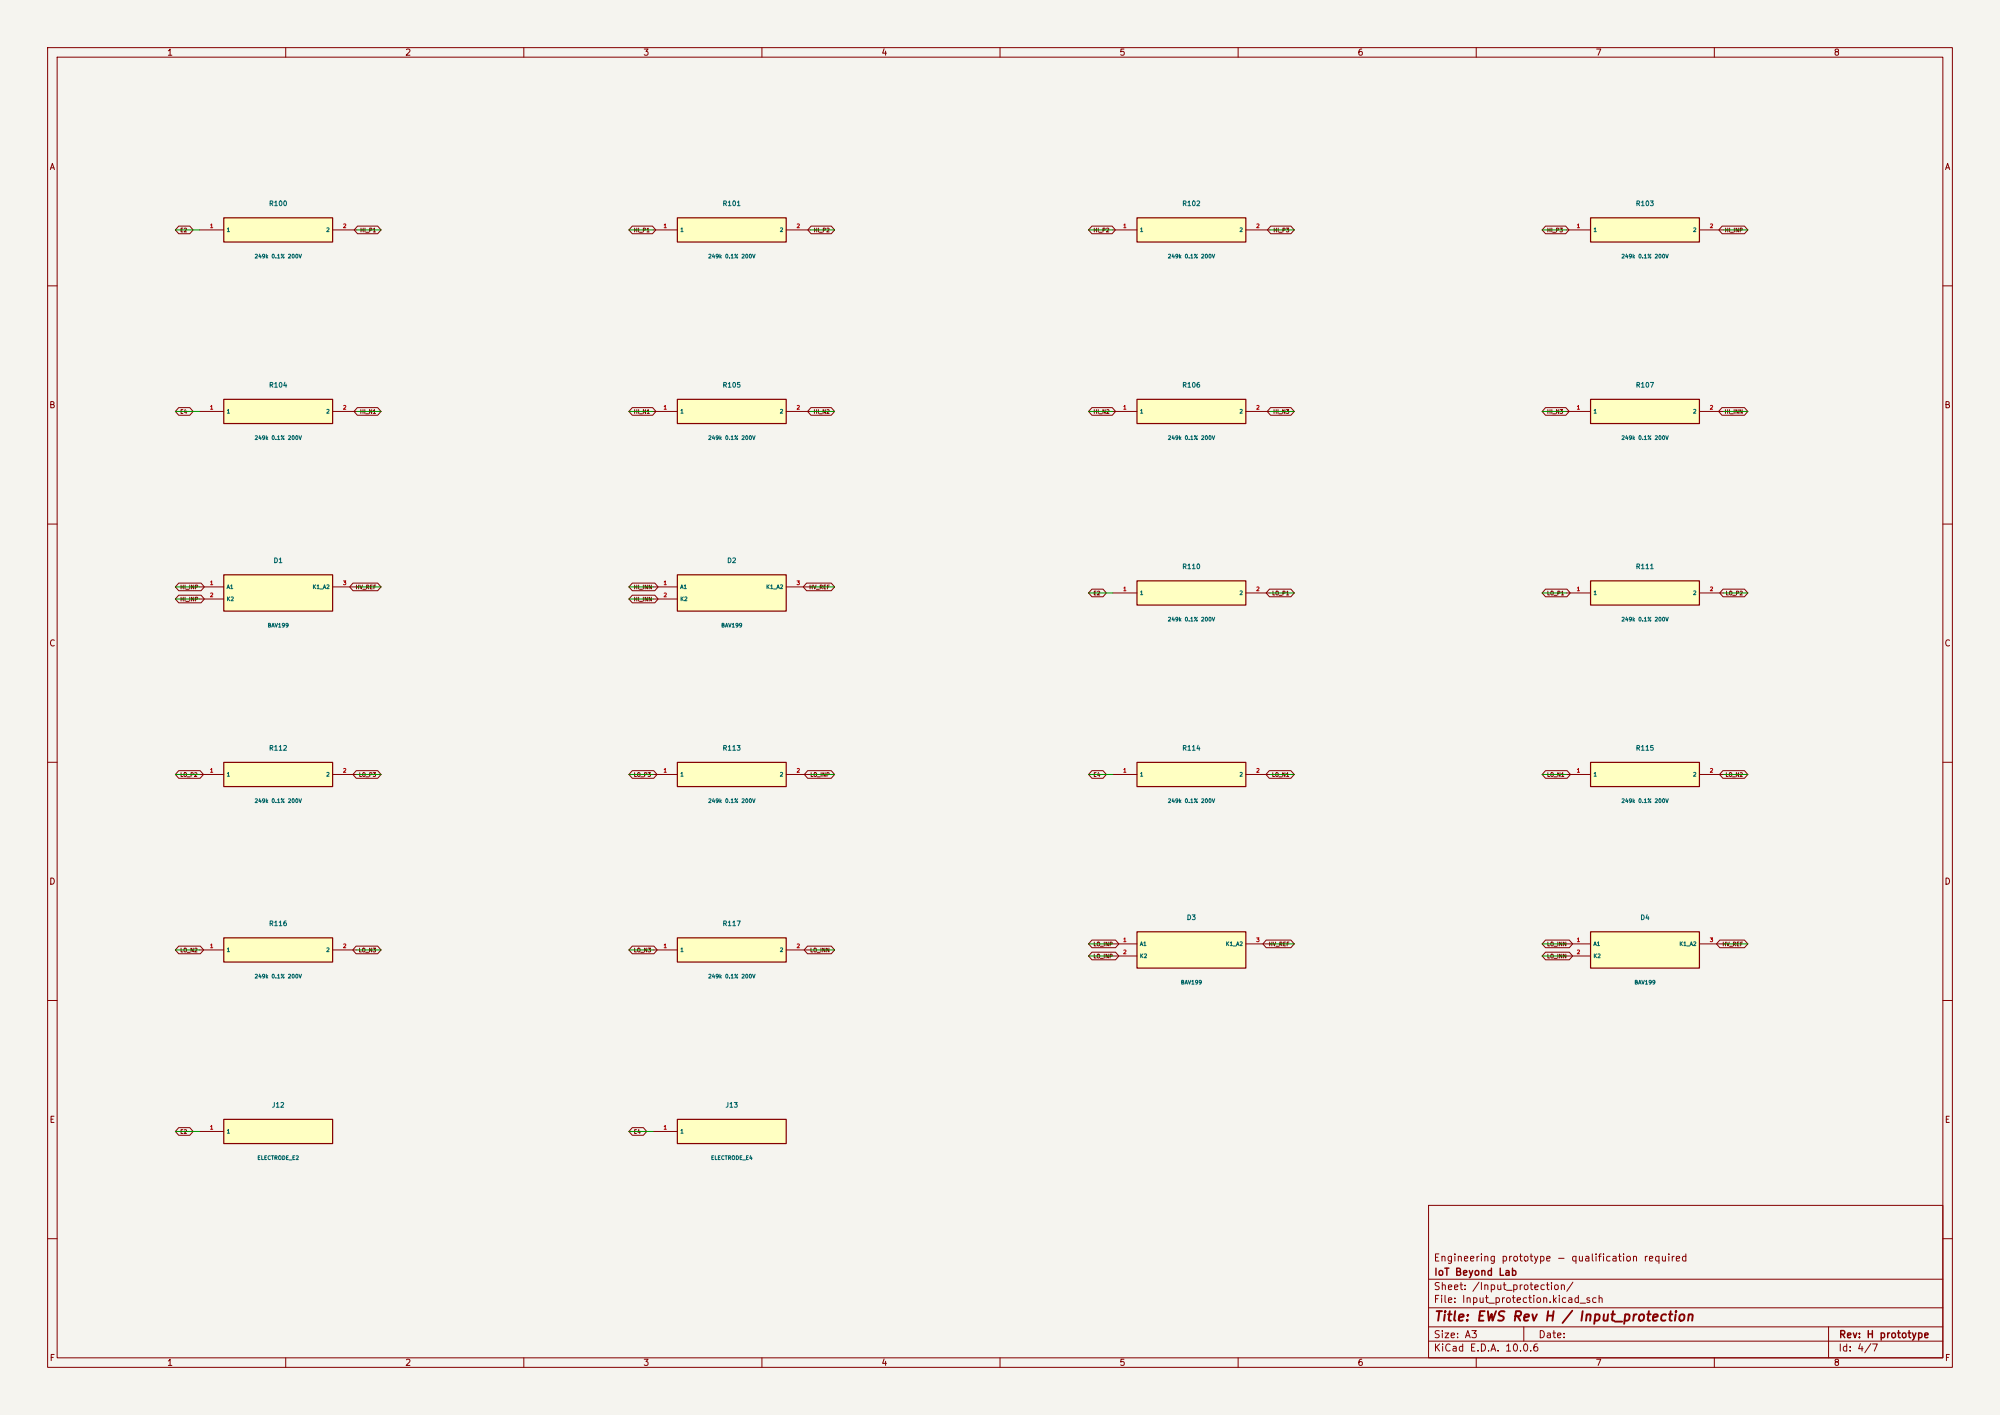
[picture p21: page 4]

Engineering prototype - qualification required
IoT Beyond Lab
Sheet: /Input_protection/
File: Input_protection.kicad_sch
Title: EWS Rev H / Input_protection

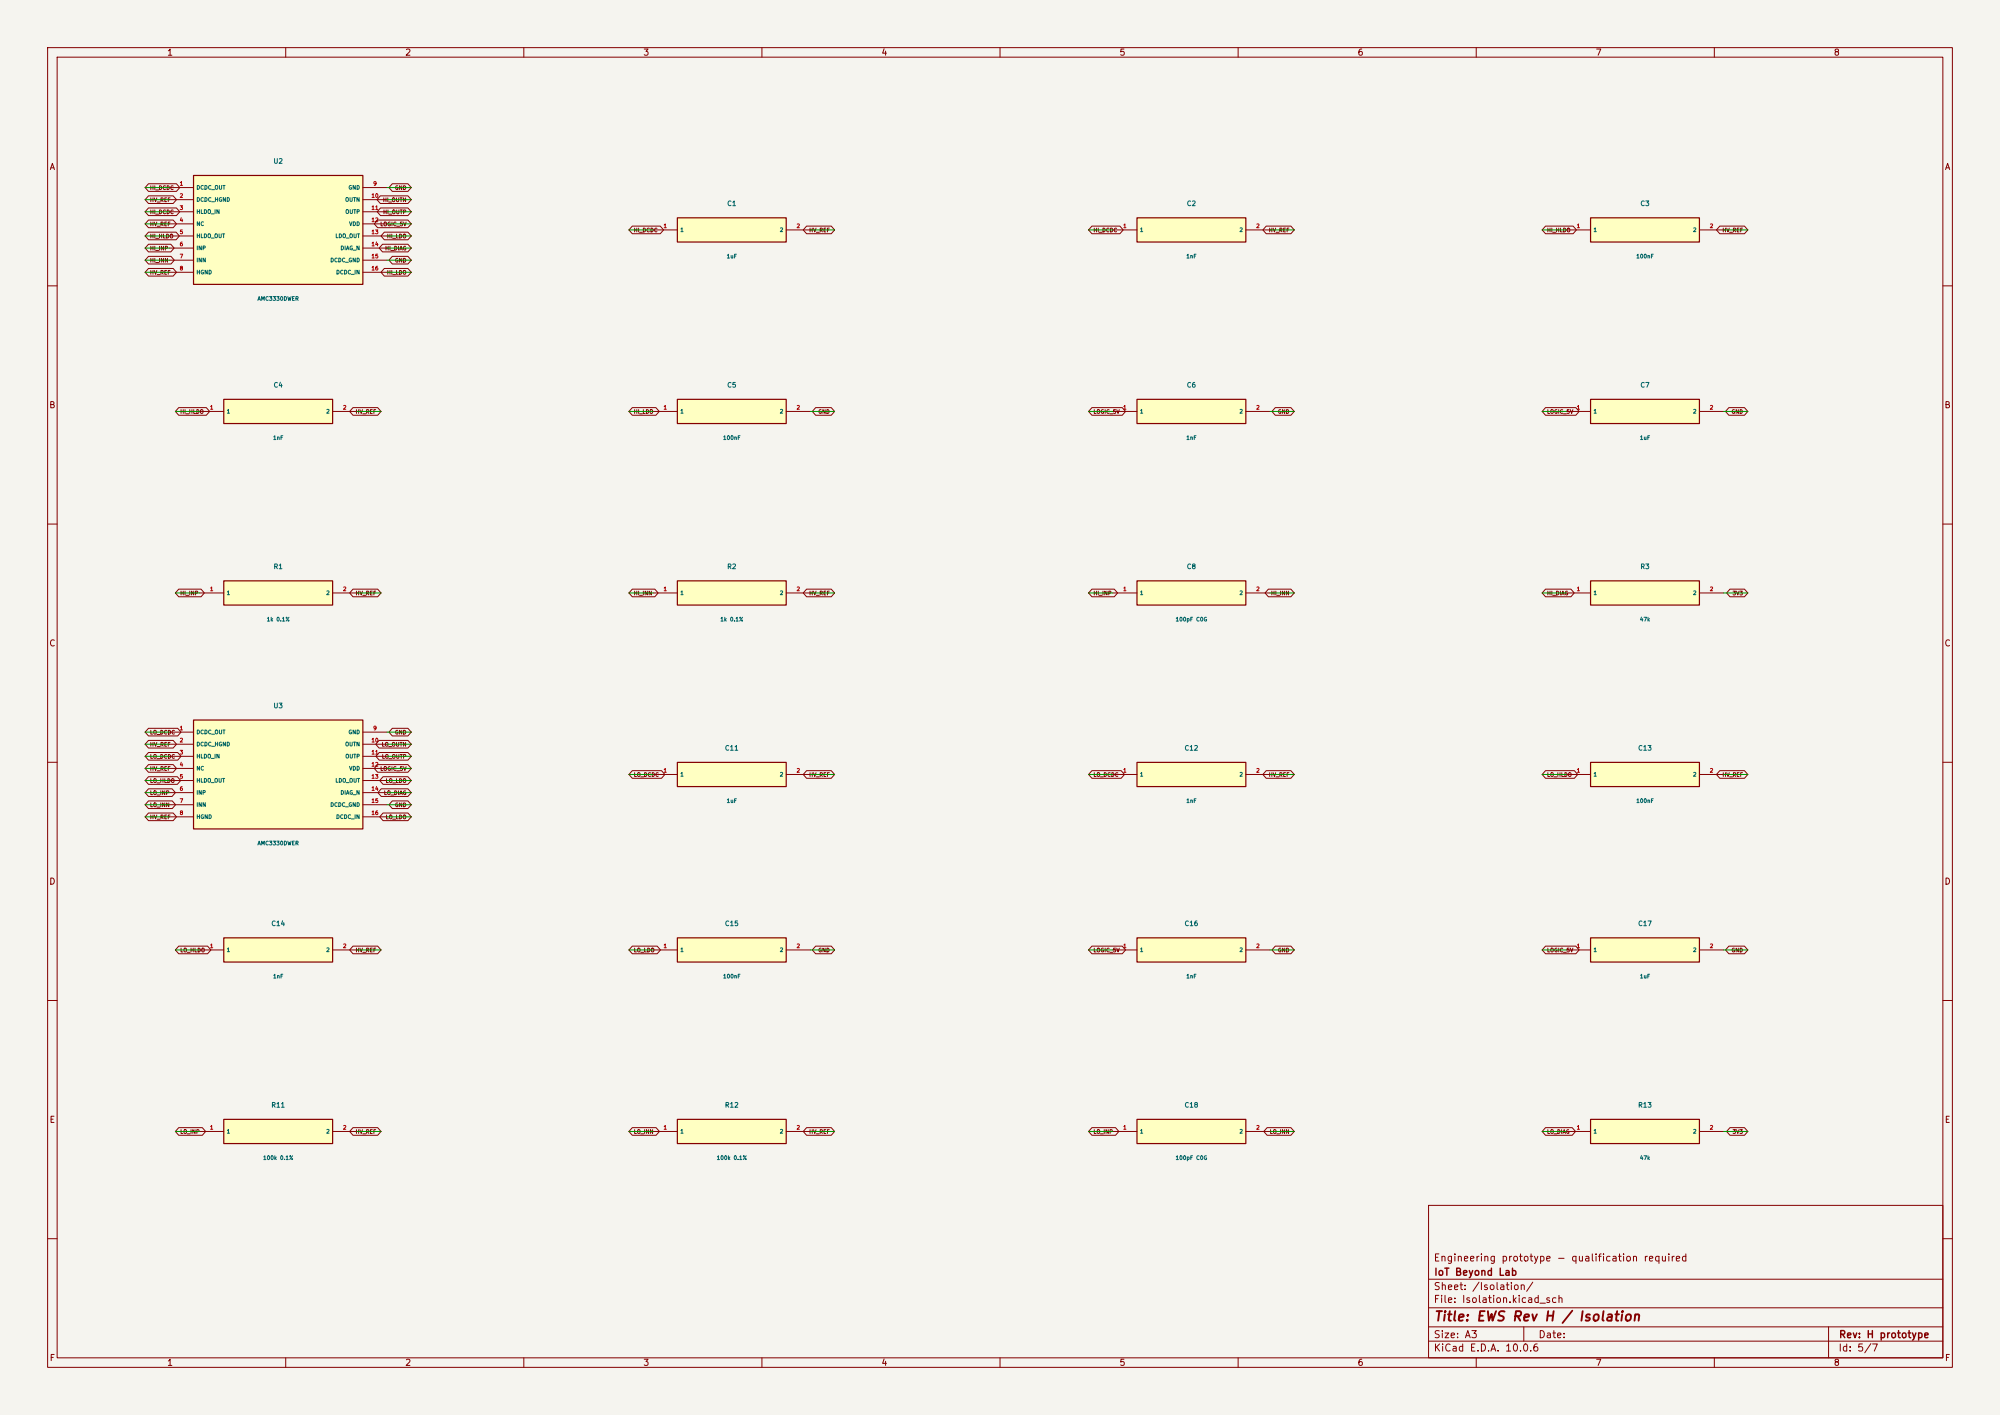
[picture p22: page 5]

Engineering prototype - qualification required
IoT Beyond Lab
Sheet: /Isolation/
File: Isolation.kicad_sch
Title: EWS Rev H / Isolation

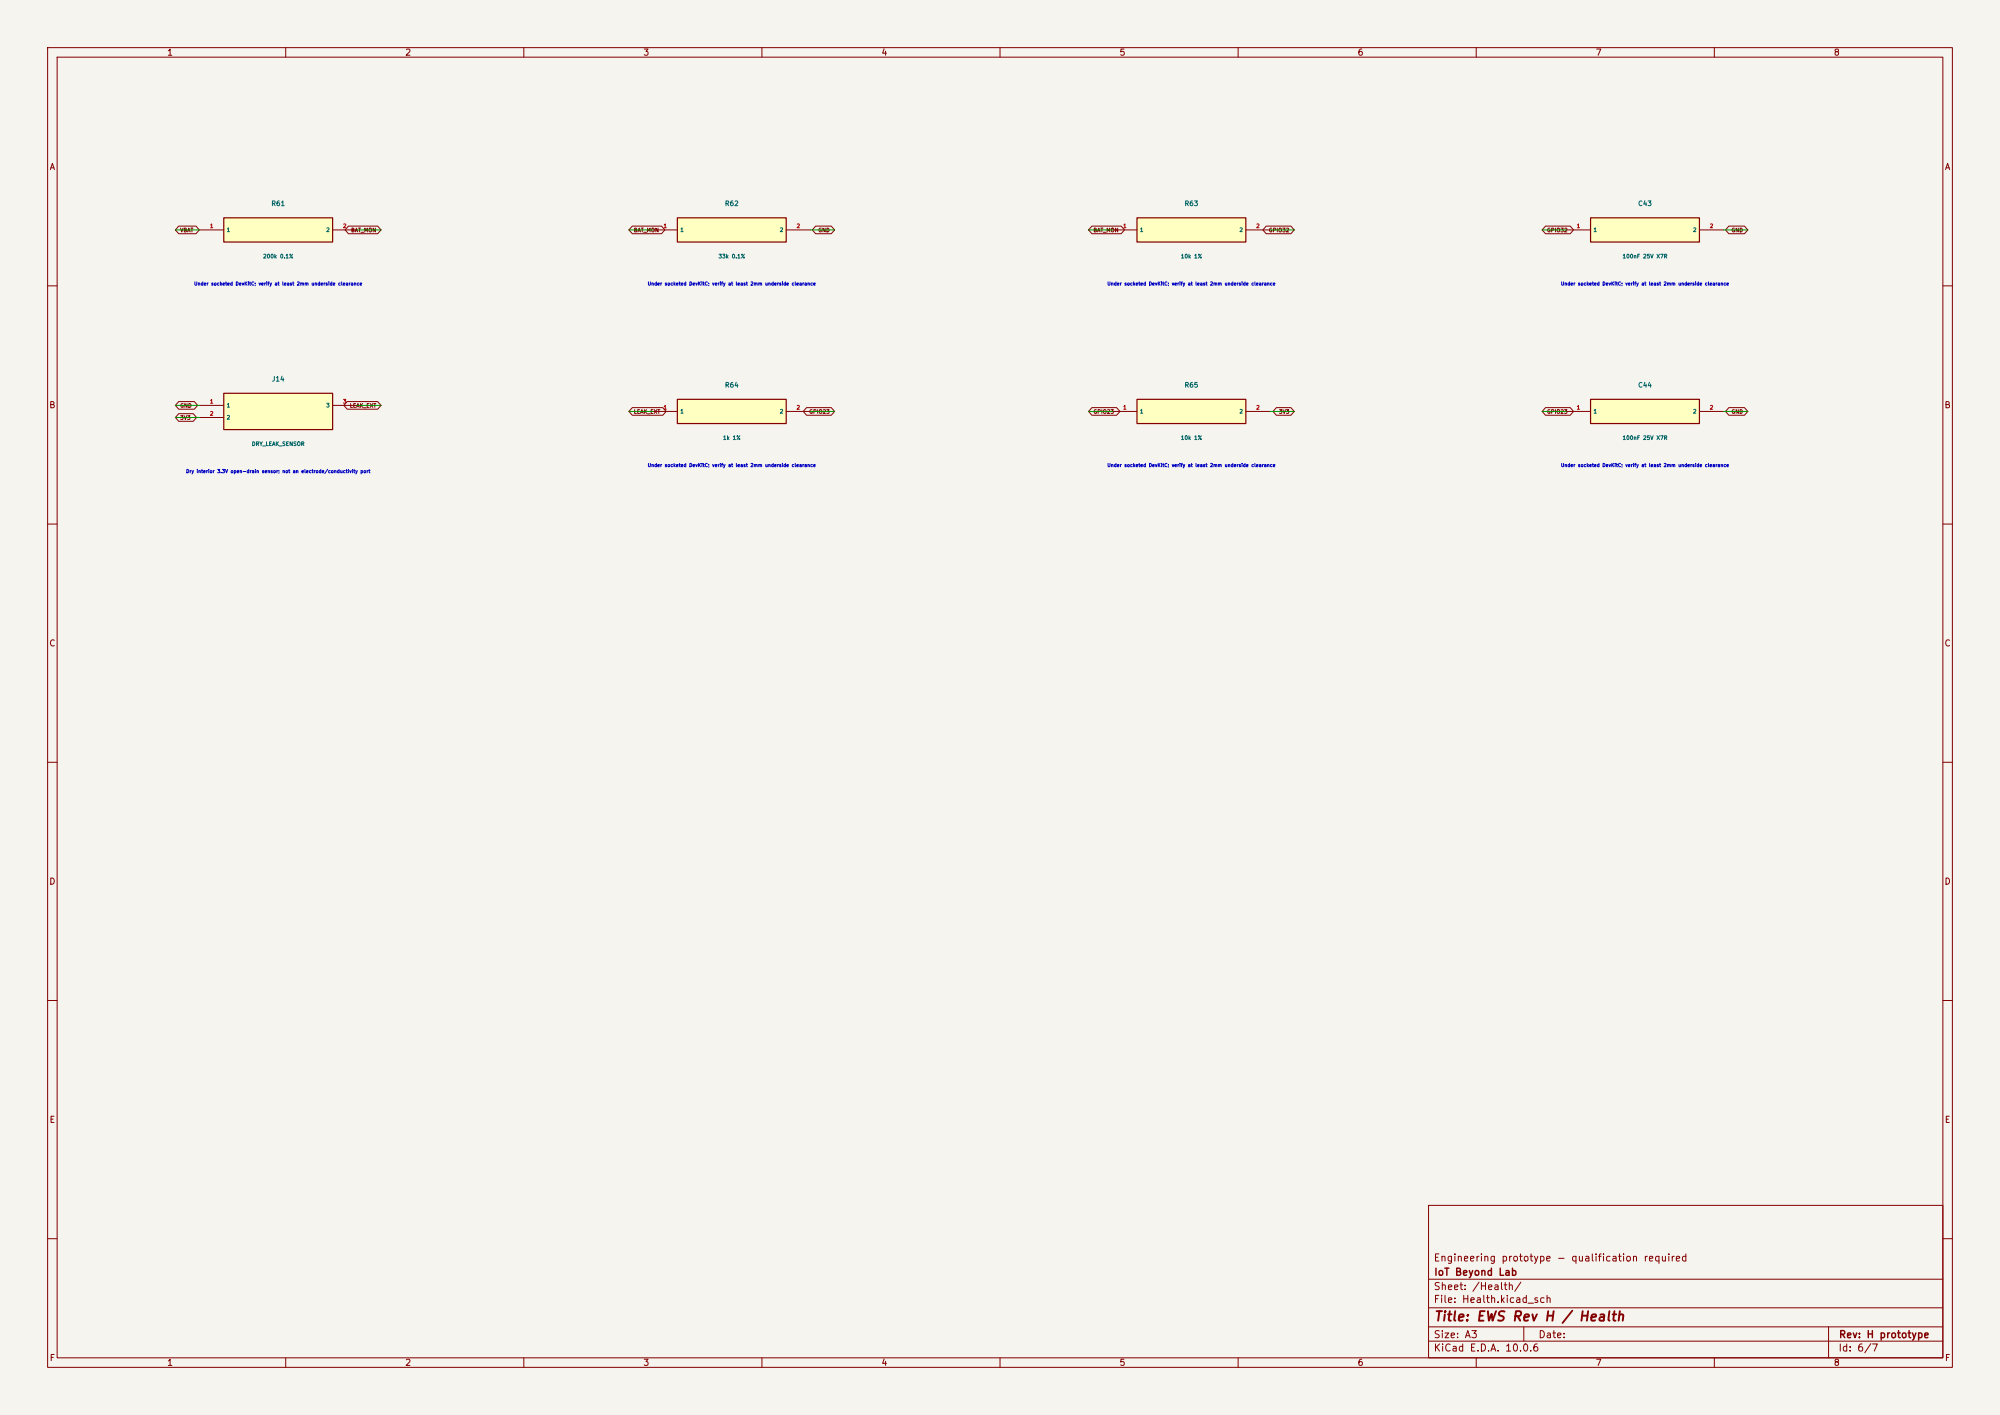
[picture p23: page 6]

Engineering prototype - qualification required
IoT Beyond Lab
Sheet: /Health/
File: Health.kicad_sch
Title: EWS Rev H / Health

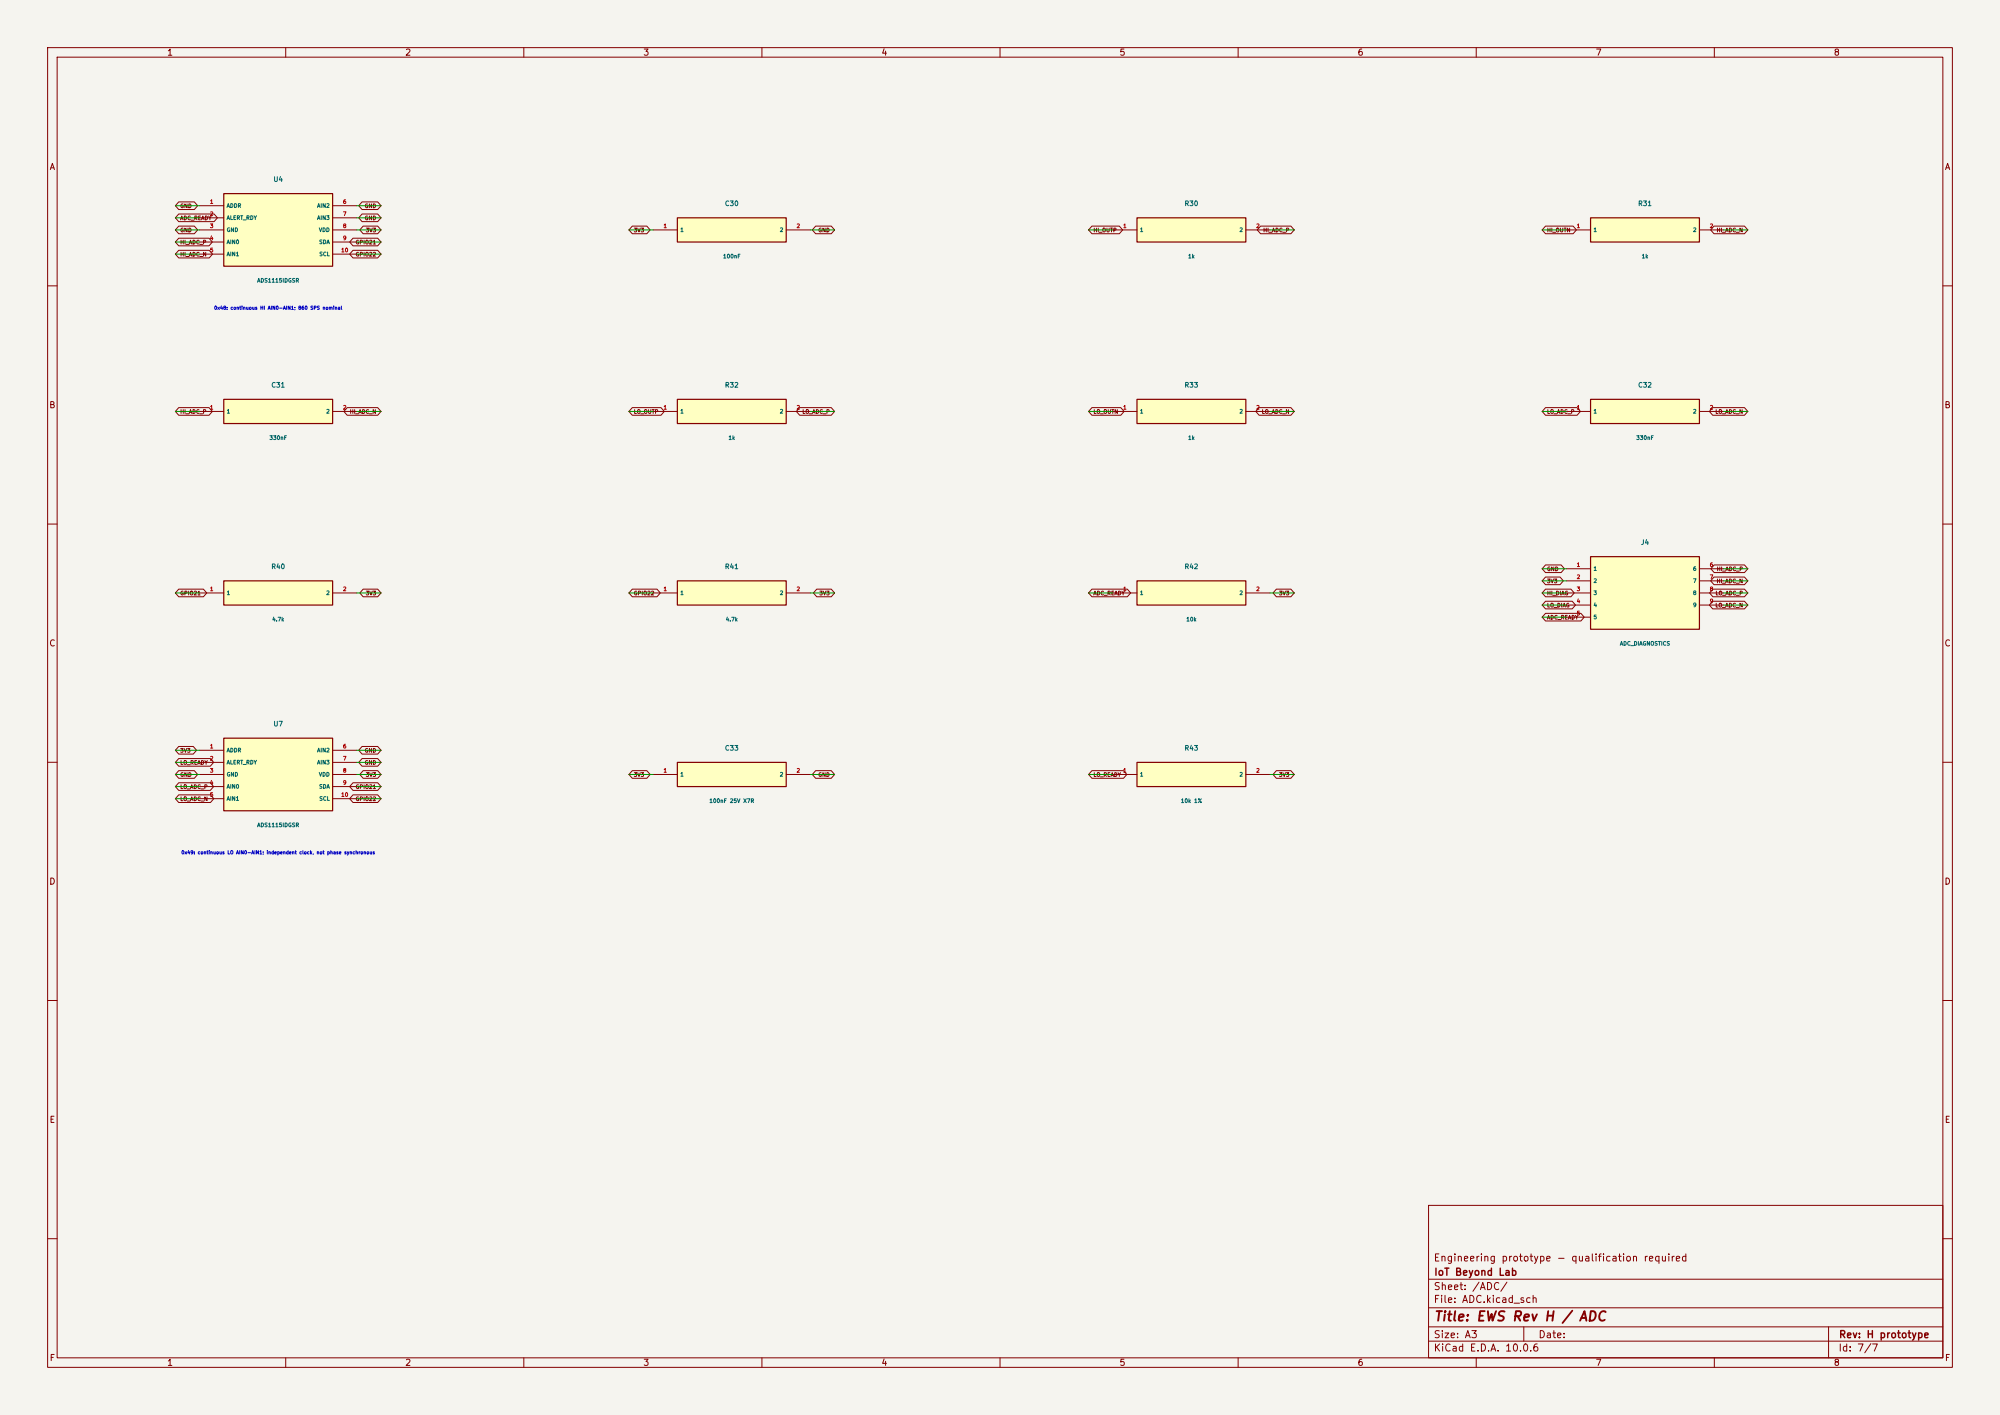
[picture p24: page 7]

0x48: continuous HI AIN0-AIN1; 860 SPS nominal

0x49: continuous LO AIN0-AIN1; independent clock, not phase synchronous

Engineering prototype - qualification required
IoT Beyond Lab
Sheet: /ADC/
File: ADC.kicad_sch
Title: EWS Rev H / ADC

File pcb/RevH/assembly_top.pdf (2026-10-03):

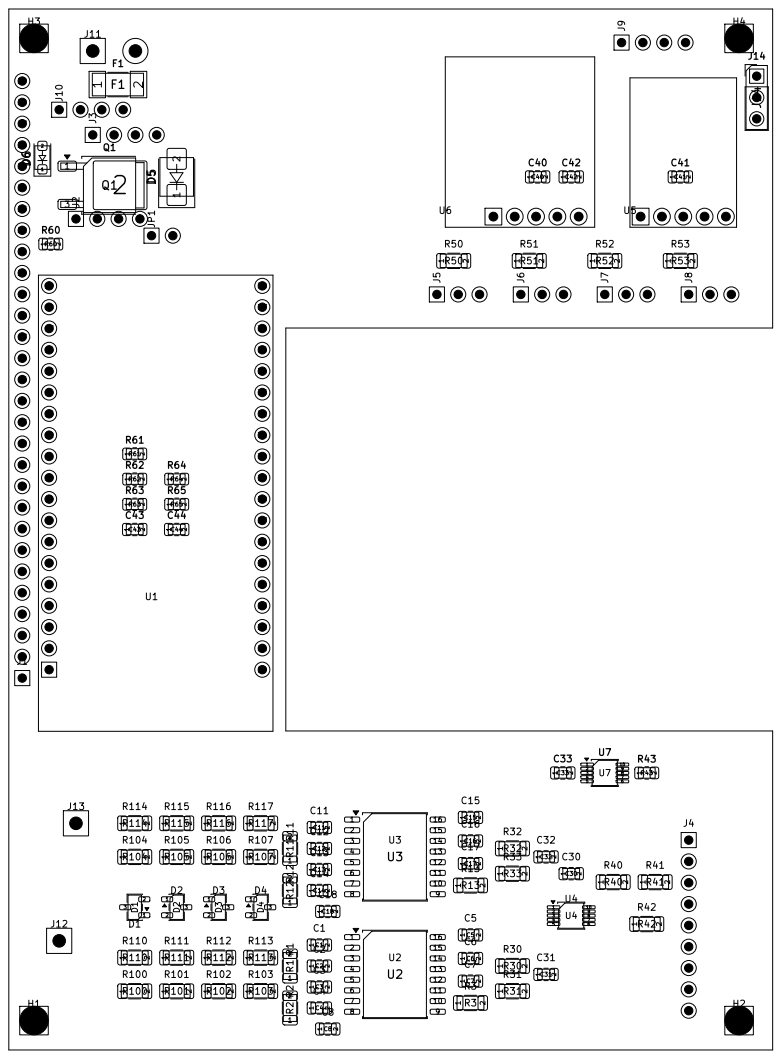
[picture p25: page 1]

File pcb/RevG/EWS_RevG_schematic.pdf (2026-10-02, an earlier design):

1 | 2 | 3 | 4 | 5 | 6 | 7 | 8

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
# F Date:

KiCad E.D.A. 10.0.6 | Id: 1/6
Size: A3 | Rev: G - engineering prototype

# Title: EWS Rev G / System overview

# File: EWS_RevG.kicad_sch

# Sheet: /

# IoT Beyond Lab

# Not qualified for energized-water use; see design and validation record

Control File: Control.kicad_sch | Power File: Power.kicad_sch

## Input_protection

### File: Input_protection.kicad_sch

## Isolation

File: Isolation.kicad_sch | ADC

### File: ADC.kicad_sch

Two electrodes E2/E4 -> four-resistor-per-leg input networks -> dual AMC3330 isolated paths -> ADS1115 -> ESP32. HI: 997:1 divider; 600 VAC RMS design target. LO: 10.96:1 divider; use conservative +/-2 V working range before characterization. Both ranges continuously connected. Sensitive path clamps during a fault; test leakage, gain error, saturation and recovery. External fused 2S harness feeds PCB logic/servos; motor/ESC high-current power stays off PCB. Never parallel ESC BEC. Remove JP1 before USB. U1 requires WROOM pin availability. Expansion signals are 3.3 V only. No CAT rating, surge qualification, water-safety threshold or guaranteed detection floor is claimed.

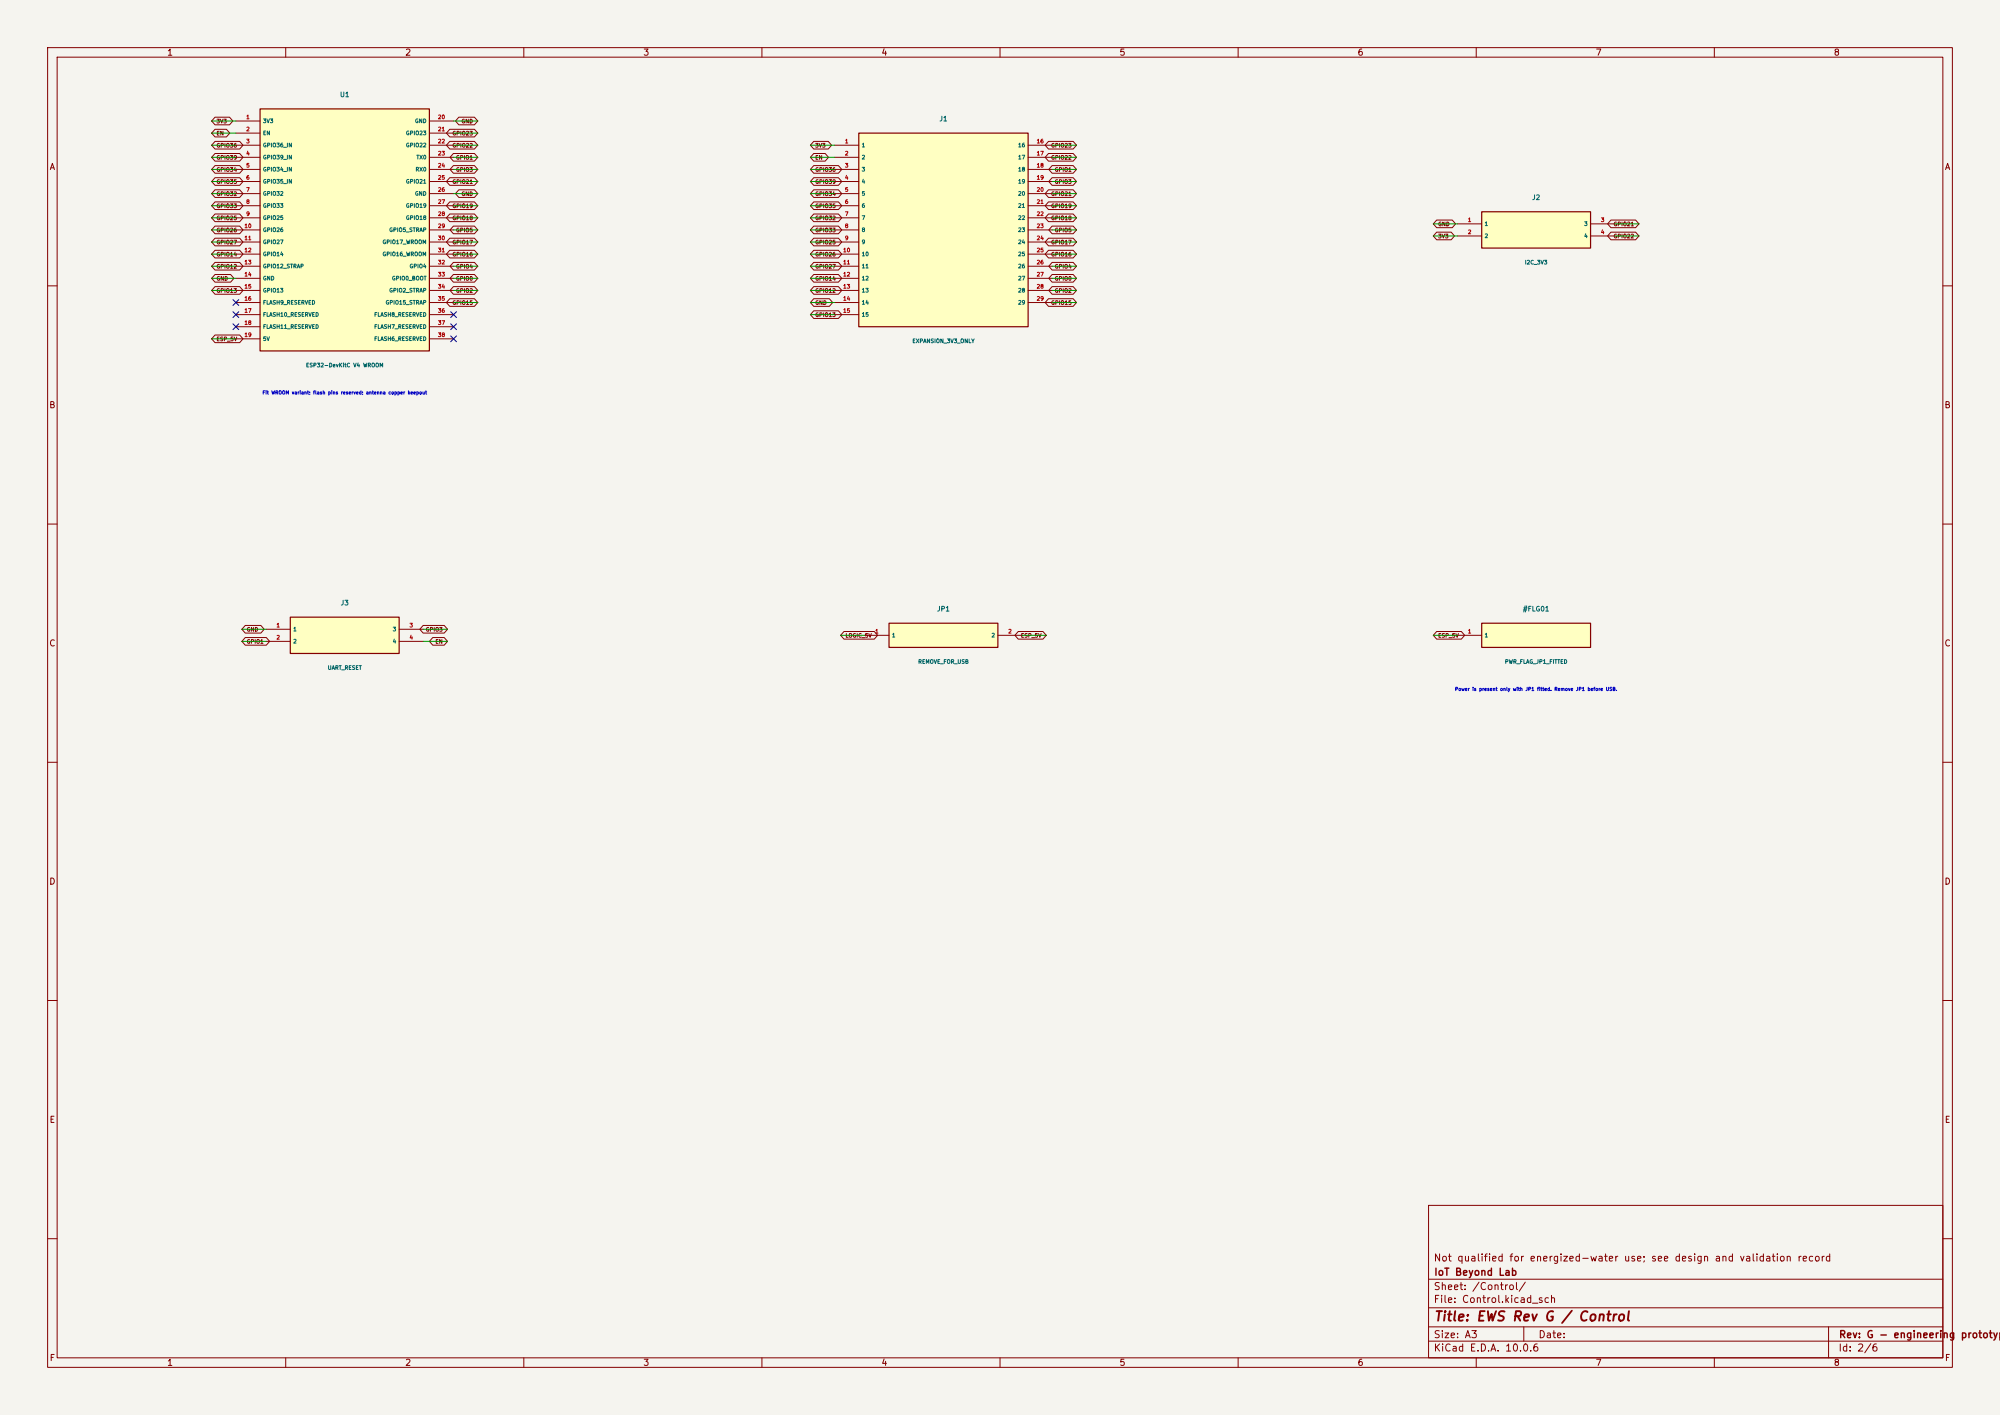
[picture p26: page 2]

Not qualified for energized-water use; see design and validation record
IoT Beyond Lab
Sheet: /Control/
File: Control.kicad_sch
Title: EWS Rev G / Control

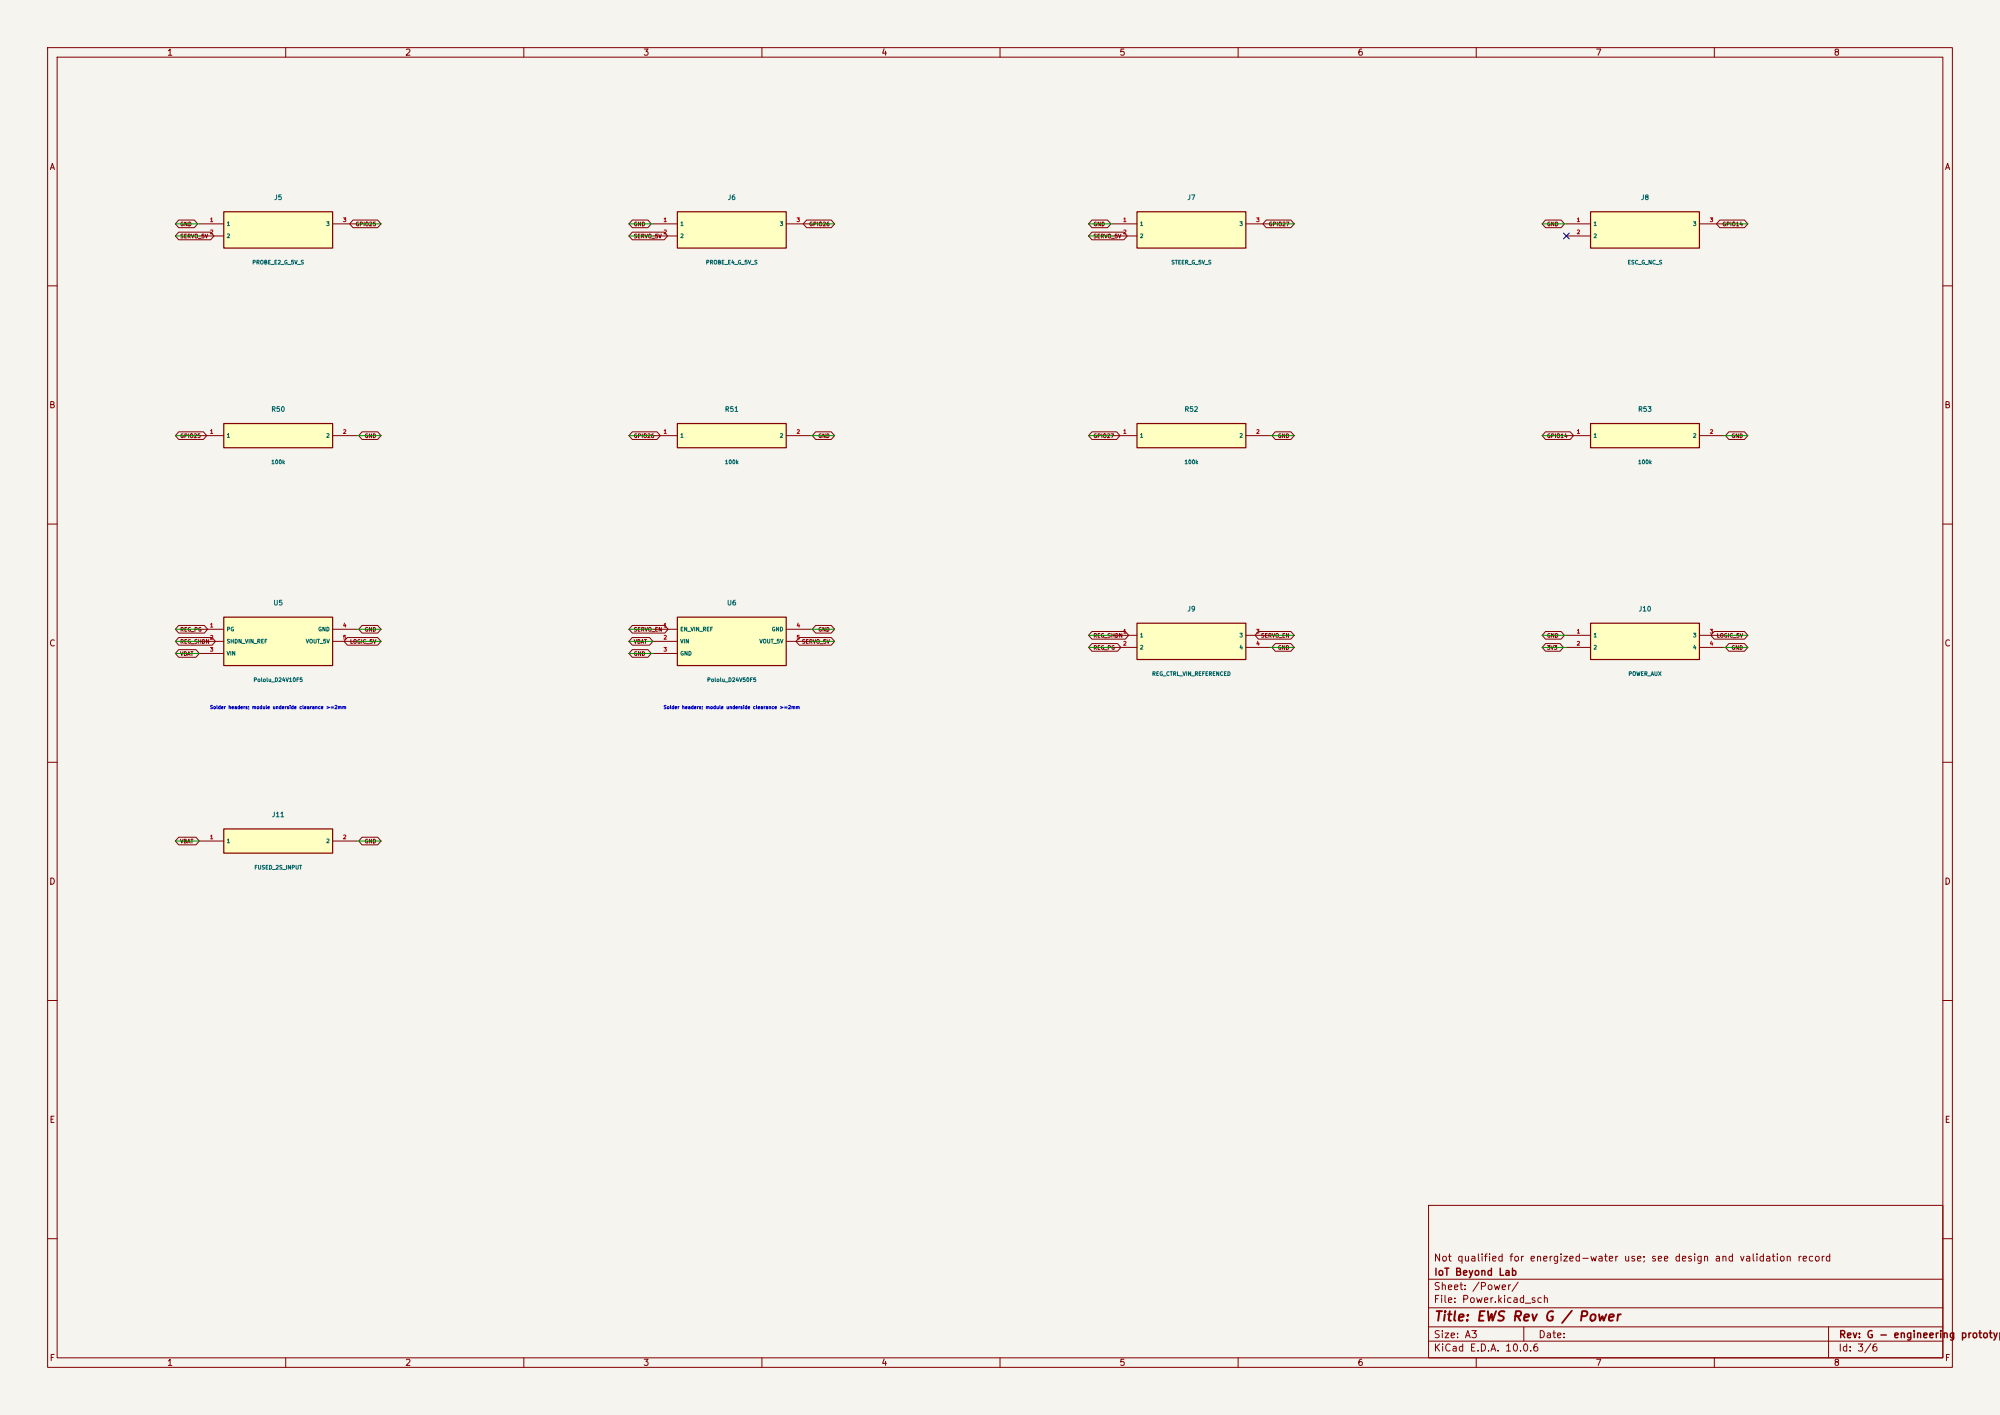
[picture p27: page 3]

Not qualified for energized-water use; see design and validation record
IoT Beyond Lab
Sheet: /Power/
File: Power.kicad_sch
Title: EWS Rev G / Power

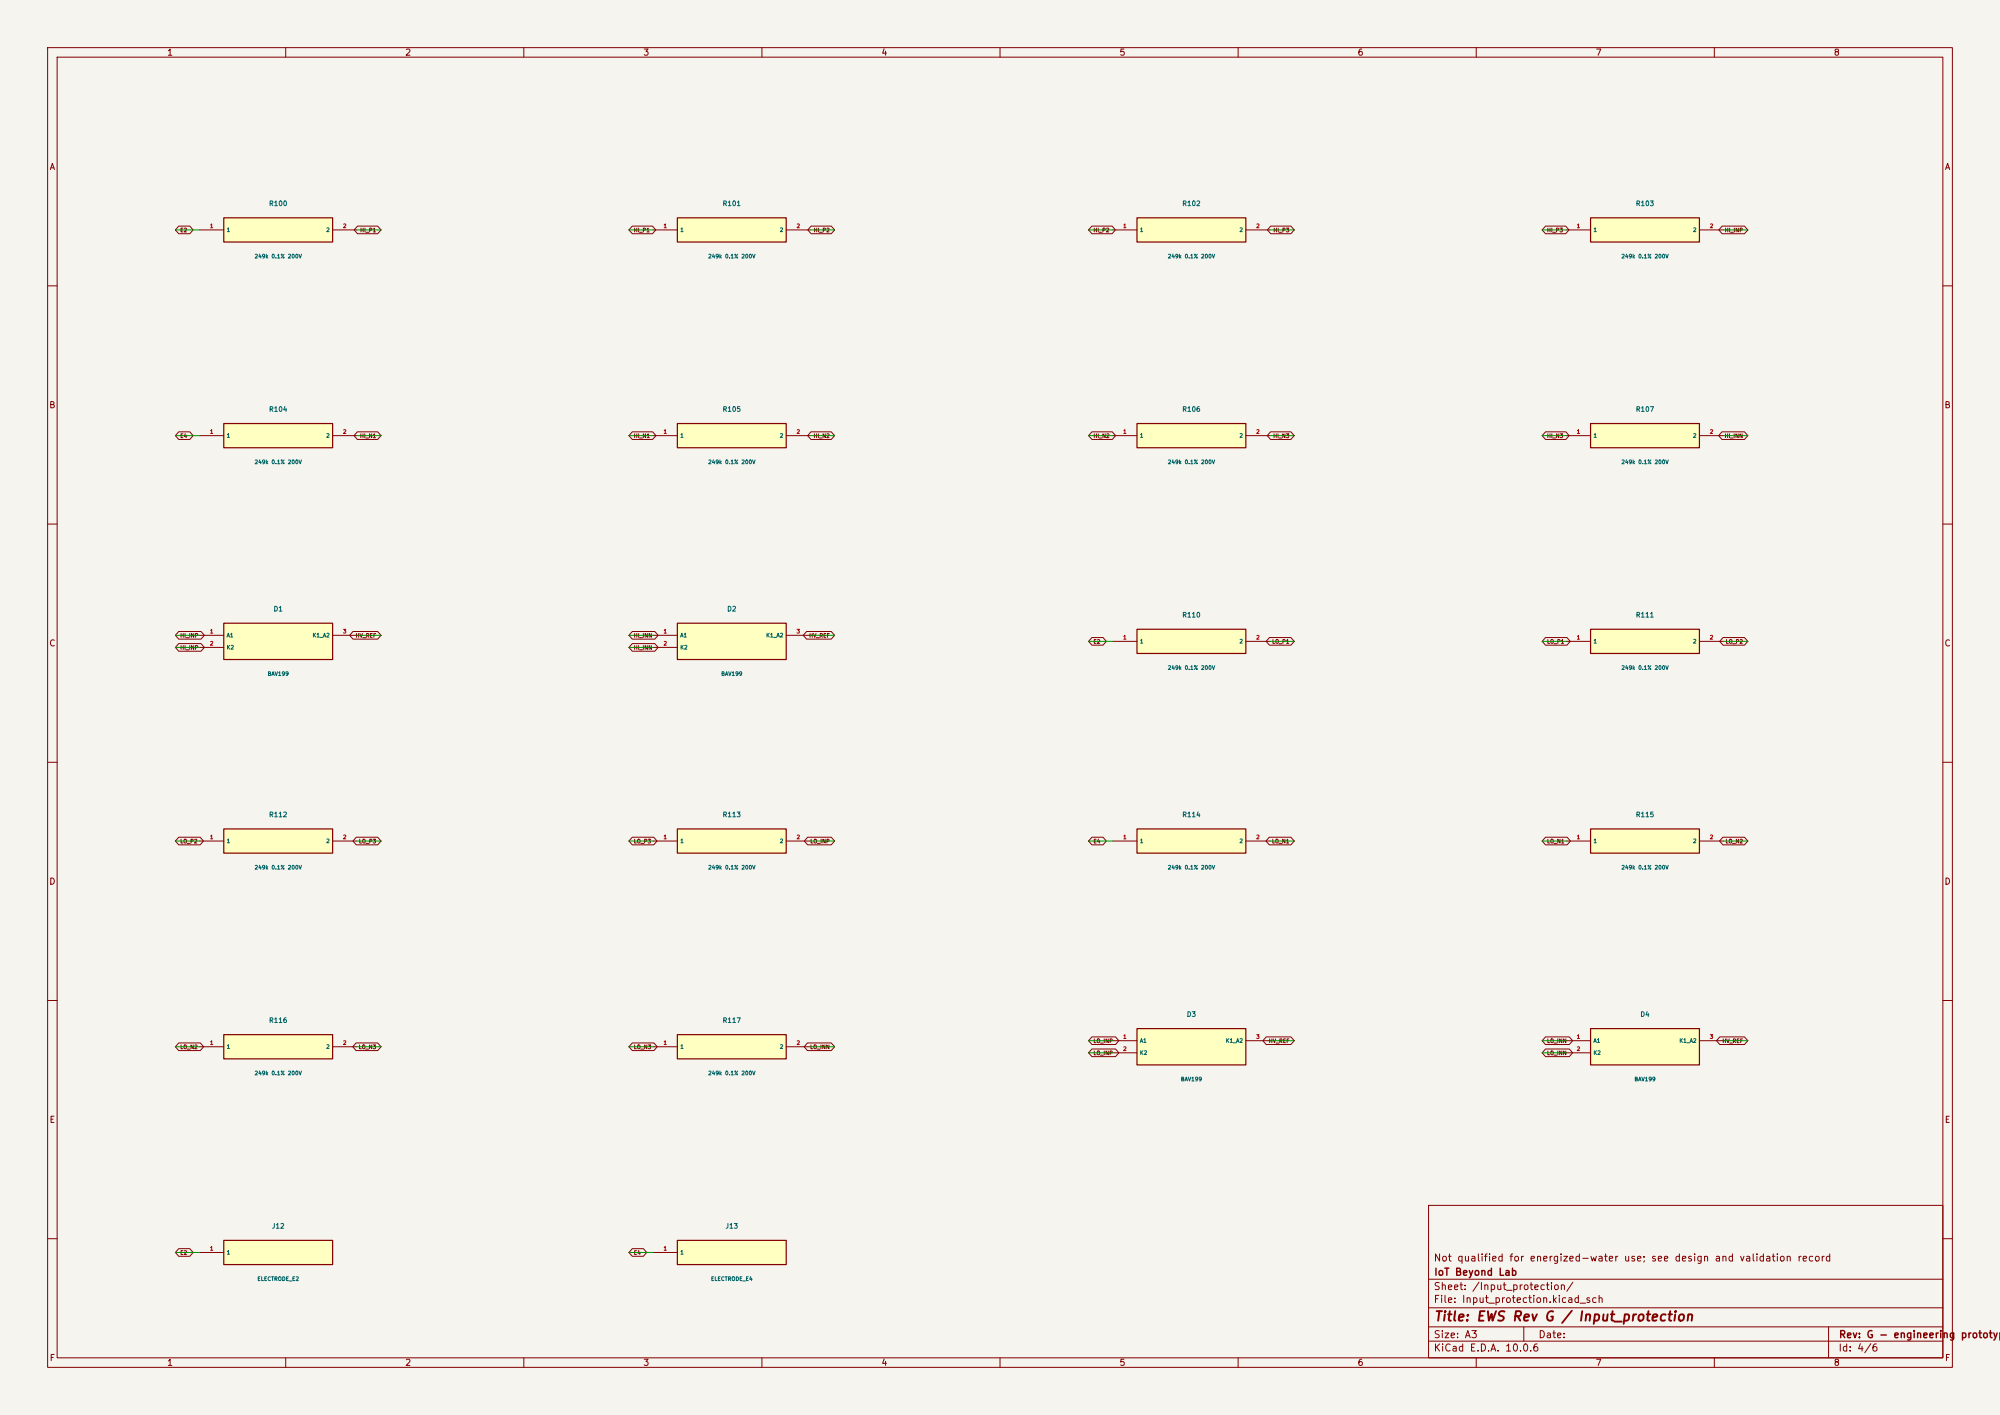
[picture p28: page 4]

Not qualified for energized-water use; see design and validation record
IoT Beyond Lab
Sheet: /Input_protection/
File: Input_protection.kicad_sch
Title: EWS Rev G / Input_protection

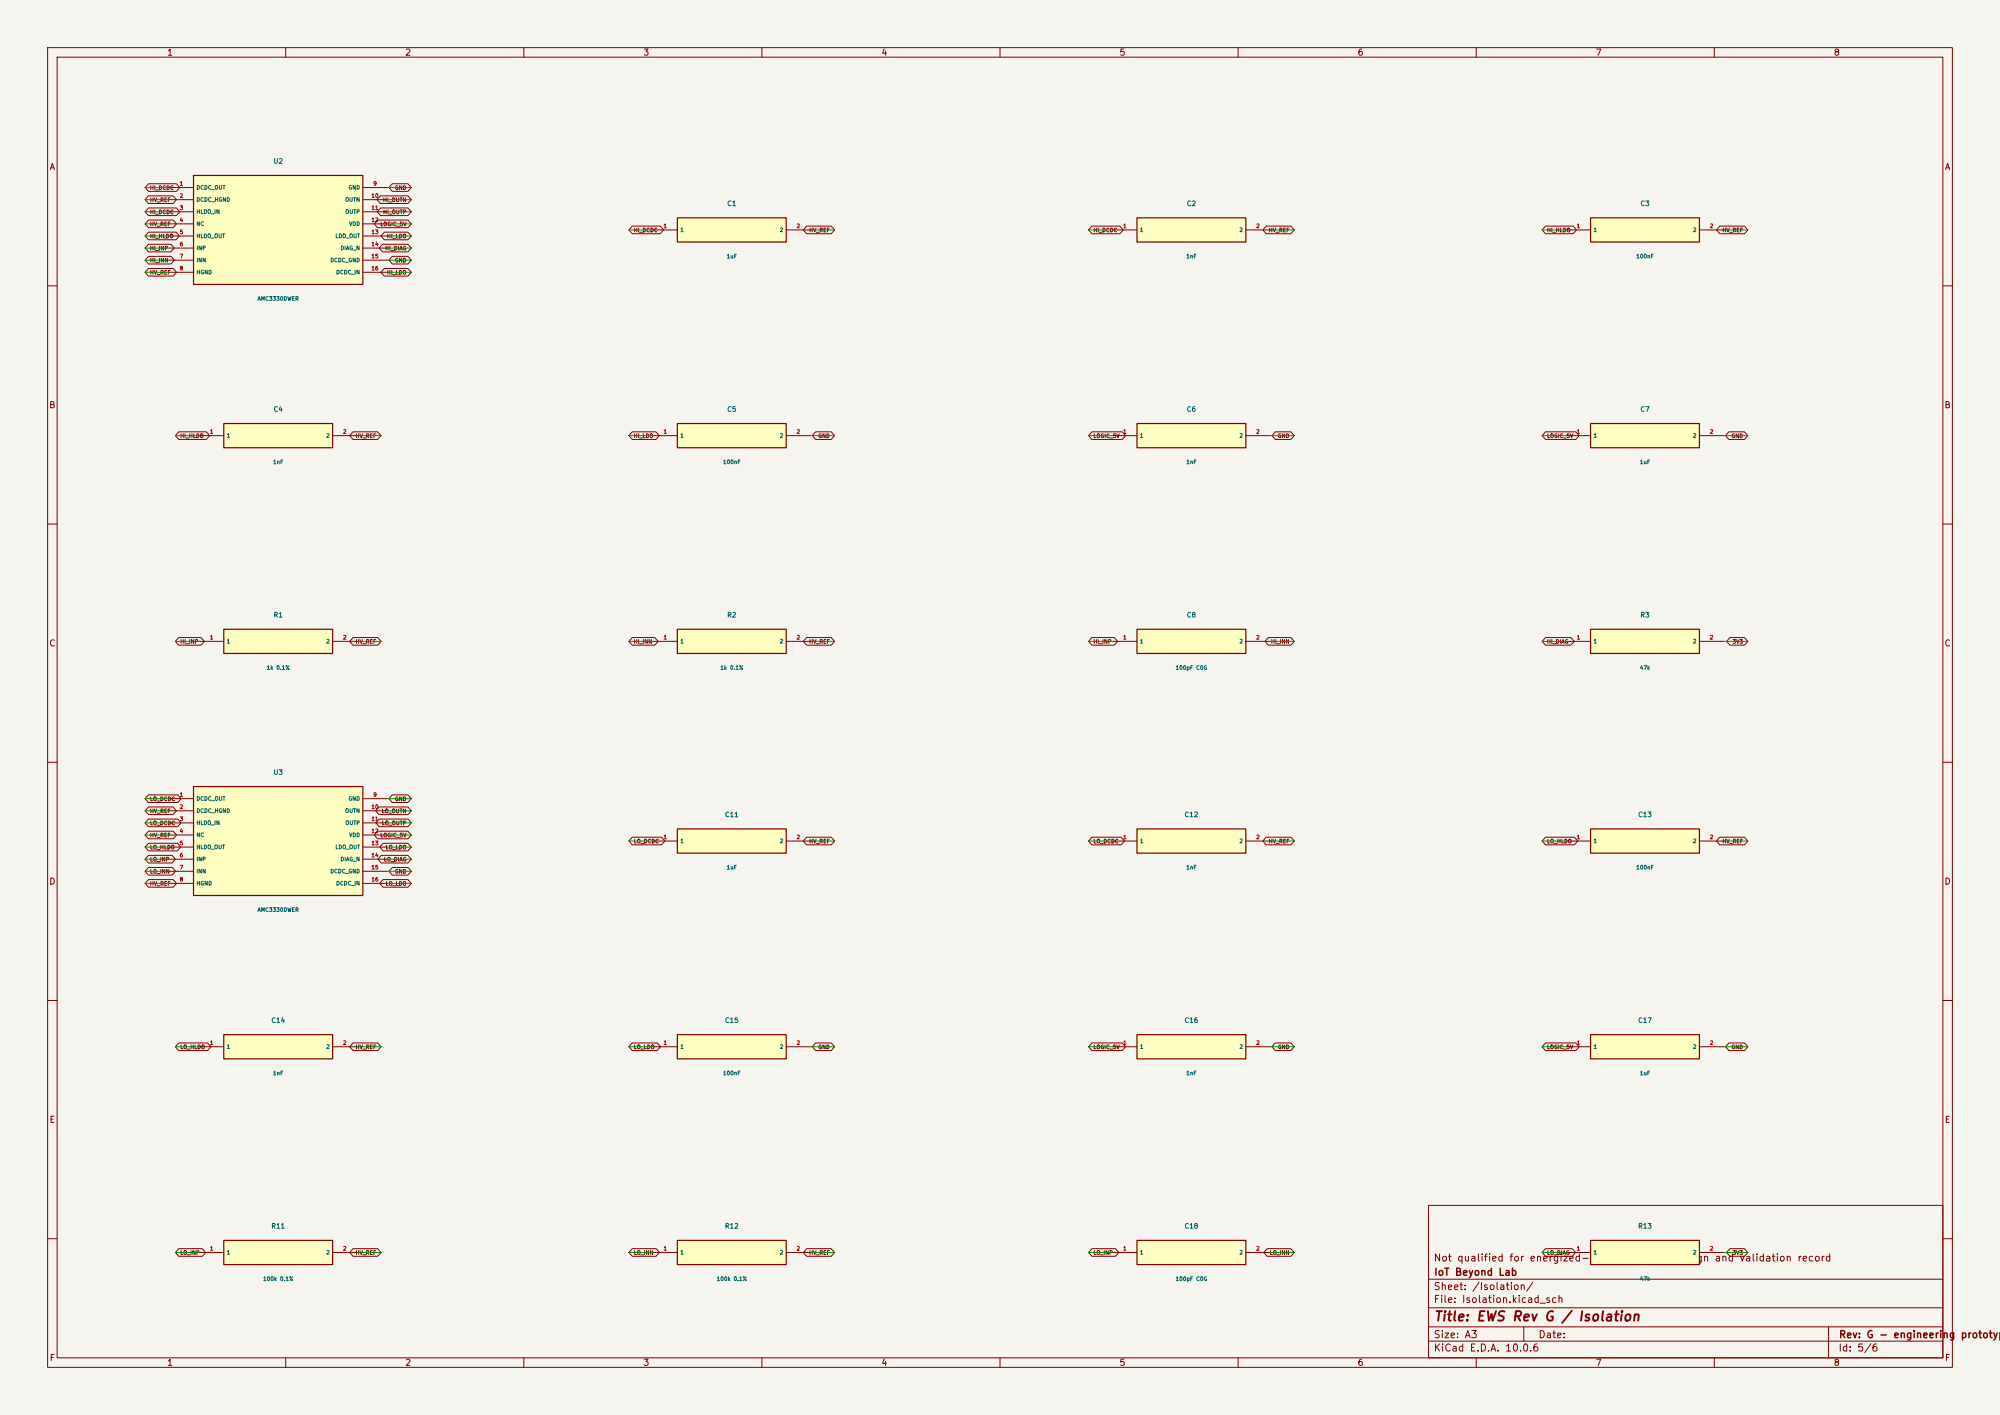
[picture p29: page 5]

Not qualified for energized-water use; see design and validation record
IoT Beyond Lab
Sheet: /Isolation/
File: Isolation.kicad_sch
Title: EWS Rev G / Isolation


Not qualified for energized-water use; see design and validation record
IoT Beyond Lab
Sheet: /ADC/
File: ADC.kicad_sch
Title: EWS Rev G / ADC


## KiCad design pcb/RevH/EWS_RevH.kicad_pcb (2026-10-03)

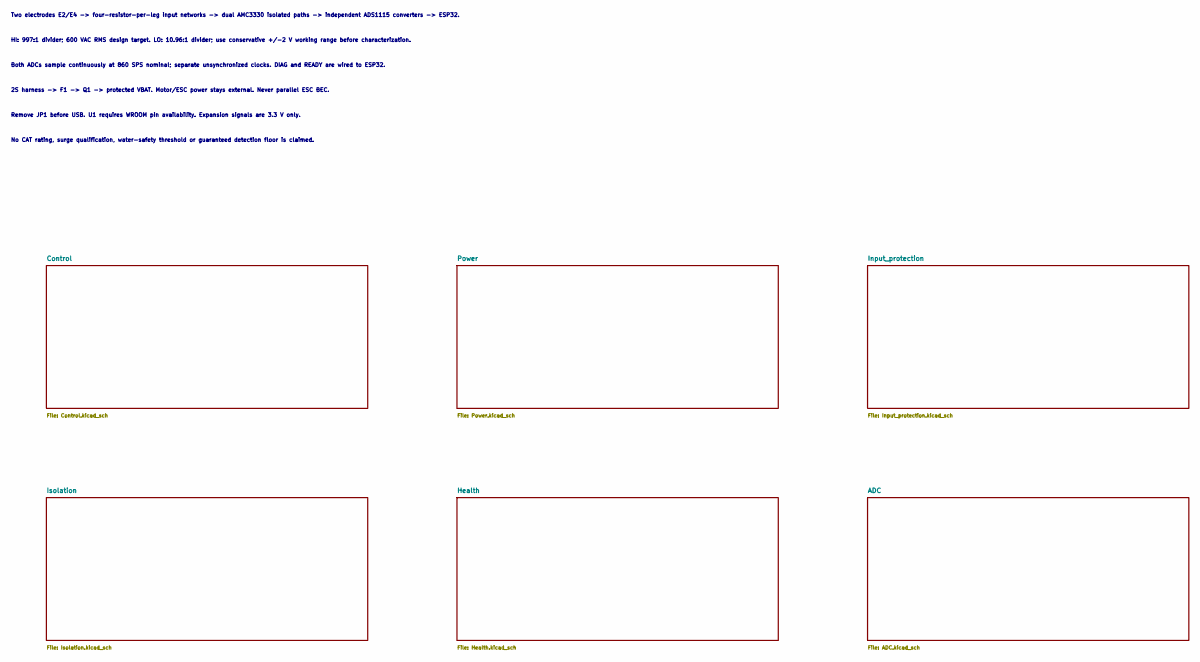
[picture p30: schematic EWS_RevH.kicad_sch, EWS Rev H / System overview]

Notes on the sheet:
Two electrodes E2/E4 -> four-resistor-per-leg input networks -> dual AMC3330 isolated paths -> independent ADS1115 converters -> ESP32.
HI: 997:1 divider; 600 VAC RMS design target. LO: 10.96:1 divider; use conservative +/-2 V working range before characterization.
Both ADCs sample continuously at 860 SPS nominal; separate unsynchronized clocks. DIAG and READY are wired to ESP32.
2S harness -> F1 -> Q1 -> protected VBAT. Motor/ESC power stays external. Never parallel ESC BEC.
Remove JP1 before USB. U1 requires WROOM pin availability. Expansion signals are 3.3 V only.
No CAT rating, surge qualification, water-safety threshold or guaranteed detection floor is claimed.

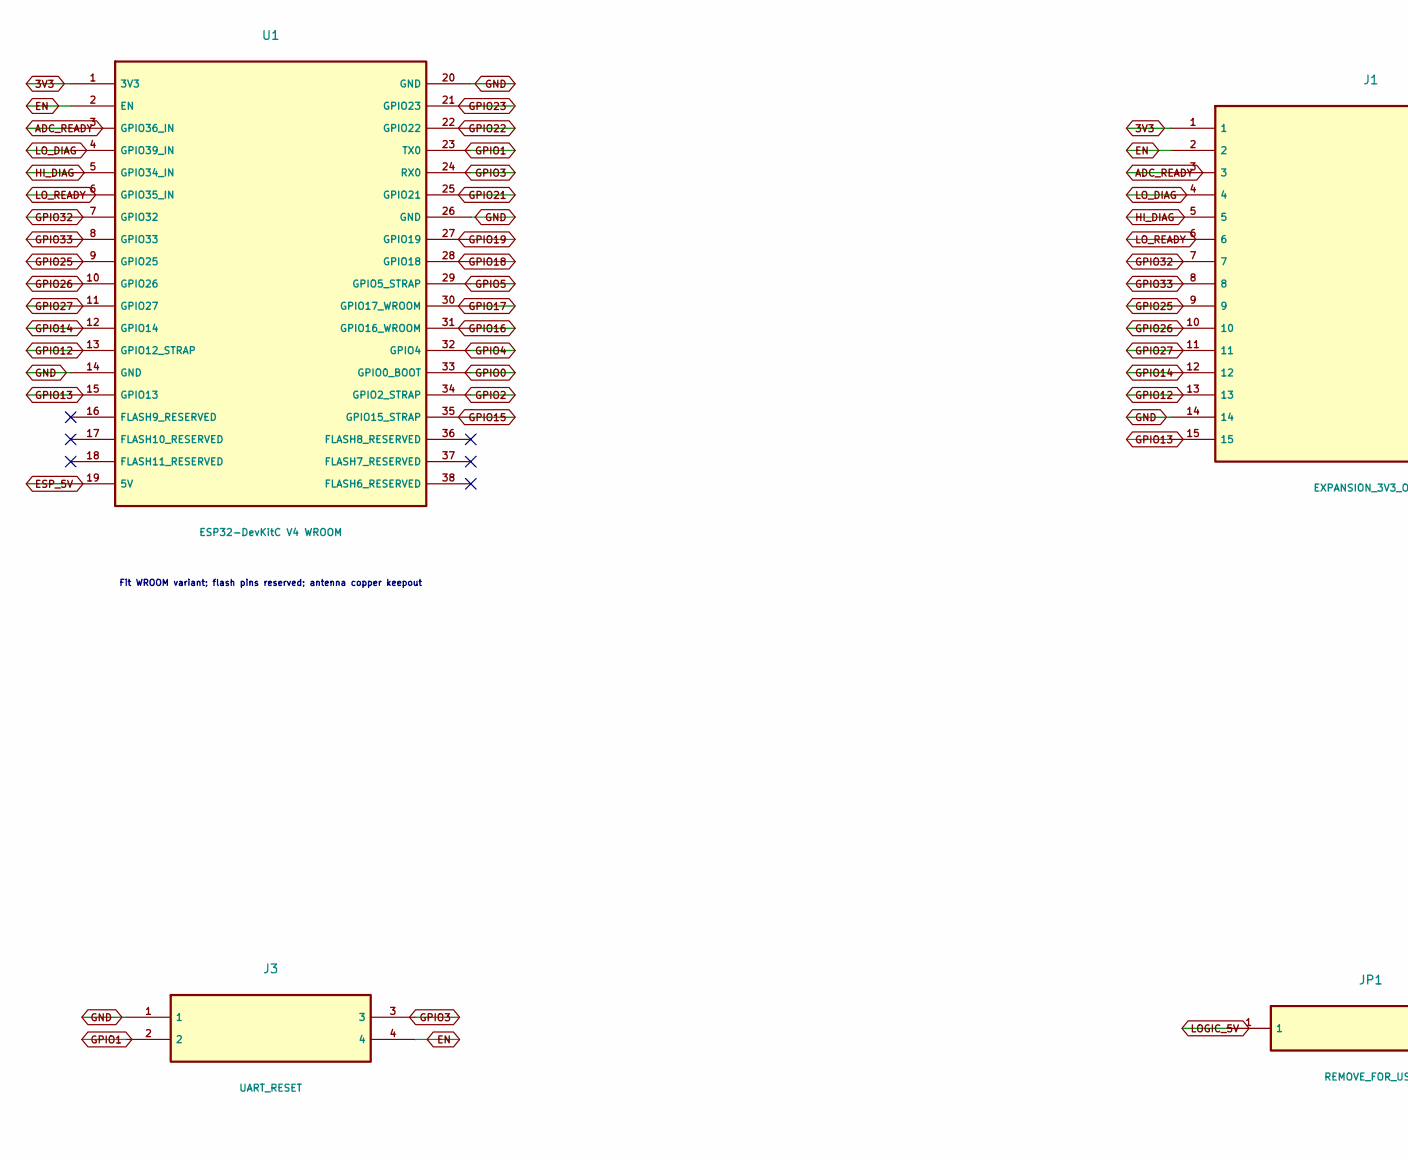
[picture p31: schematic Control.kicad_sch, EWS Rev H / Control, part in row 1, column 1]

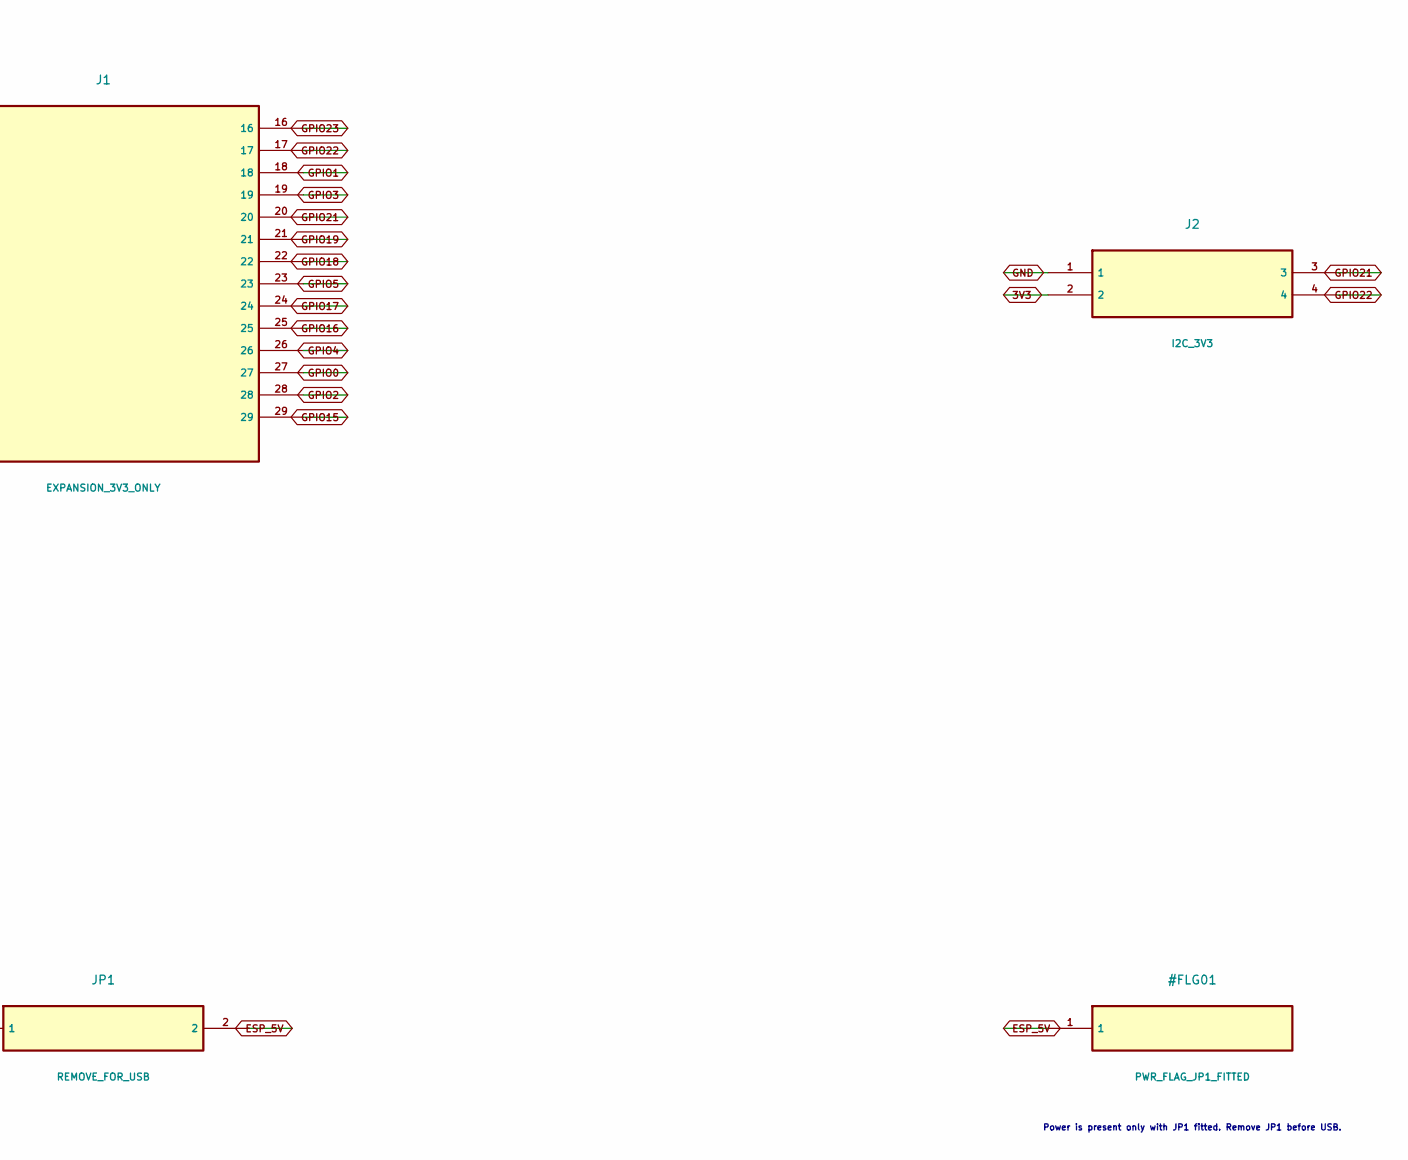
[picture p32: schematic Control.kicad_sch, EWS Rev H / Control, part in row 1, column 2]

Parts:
J1: EXPANSION_3V3_ONLY; J1
J2: I2C_3V3; J2
J3: UART_RESET; J3
JP1: REMOVE_FOR_USB; JP1
U1: ESP32-DevKitC V4 WROOM; U1

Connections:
3V3: J1.1, J2.2, U1.1 (3V3); also elsewhere on the board
ADC_READY: J1.3, U1.3 (GPIO36_IN); also elsewhere on the board
EN: J1.2, J3.4, U1.2 (EN)
ESP_5V: JP1.2, U1.19 (5V)
GND: J1.14, J2.1, J3.1, U1.14 (GND), U1.20 (GND), U1.26 (GND); also elsewhere on the board
GPIO0: J1.27, U1.33 (GPIO0_BOOT)
GPIO1: J1.18, J3.2, U1.23 (TX0)
GPIO2: J1.28, U1.34 (GPIO2_STRAP)
GPIO3: J1.19, J3.3, U1.24 (RX0)
GPIO4: J1.26, U1.32 (GPIO4)
GPIO5: J1.23, U1.29 (GPIO5_STRAP)
GPIO12: J1.13, U1.13 (GPIO12_STRAP)
GPIO13: J1.15, U1.15 (GPIO13)
GPIO14: J1.12, U1.12 (GPIO14); also elsewhere on the board
GPIO15: J1.29, U1.35 (GPIO15_STRAP)
GPIO16: J1.25, U1.31 (GPIO16_WROOM)
GPIO17: J1.24, U1.30 (GPIO17_WROOM)
GPIO18: J1.22, U1.28 (GPIO18)
GPIO19: J1.21, U1.27 (GPIO19)
GPIO21: J1.20, J2.3, U1.25 (GPIO21); also elsewhere on the board
GPIO22: J1.17, J2.4, U1.22 (GPIO22); also elsewhere on the board
GPIO23: J1.16, U1.21 (GPIO23); also elsewhere on the board
GPIO25: J1.9, U1.9 (GPIO25); also elsewhere on the board
GPIO26: J1.10, U1.10 (GPIO26); also elsewhere on the board
GPIO27: J1.11, U1.11 (GPIO27); also elsewhere on the board
GPIO32: J1.7, U1.7 (GPIO32); also elsewhere on the board
GPIO33: J1.8, U1.8 (GPIO33)
HI_DIAG: J1.5, U1.5 (GPIO34_IN); also elsewhere on the board
LOGIC_5V: JP1.1; also elsewhere on the board
LO_DIAG: J1.4, U1.4 (GPIO39_IN); also elsewhere on the board
LO_READY: J1.6, U1.6 (GPIO35_IN); also elsewhere on the board

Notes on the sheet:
Fit WROOM variant; flash pins reserved; antenna copper keepout
Power is present only with JP1 fitted. Remove JP1 before USB.

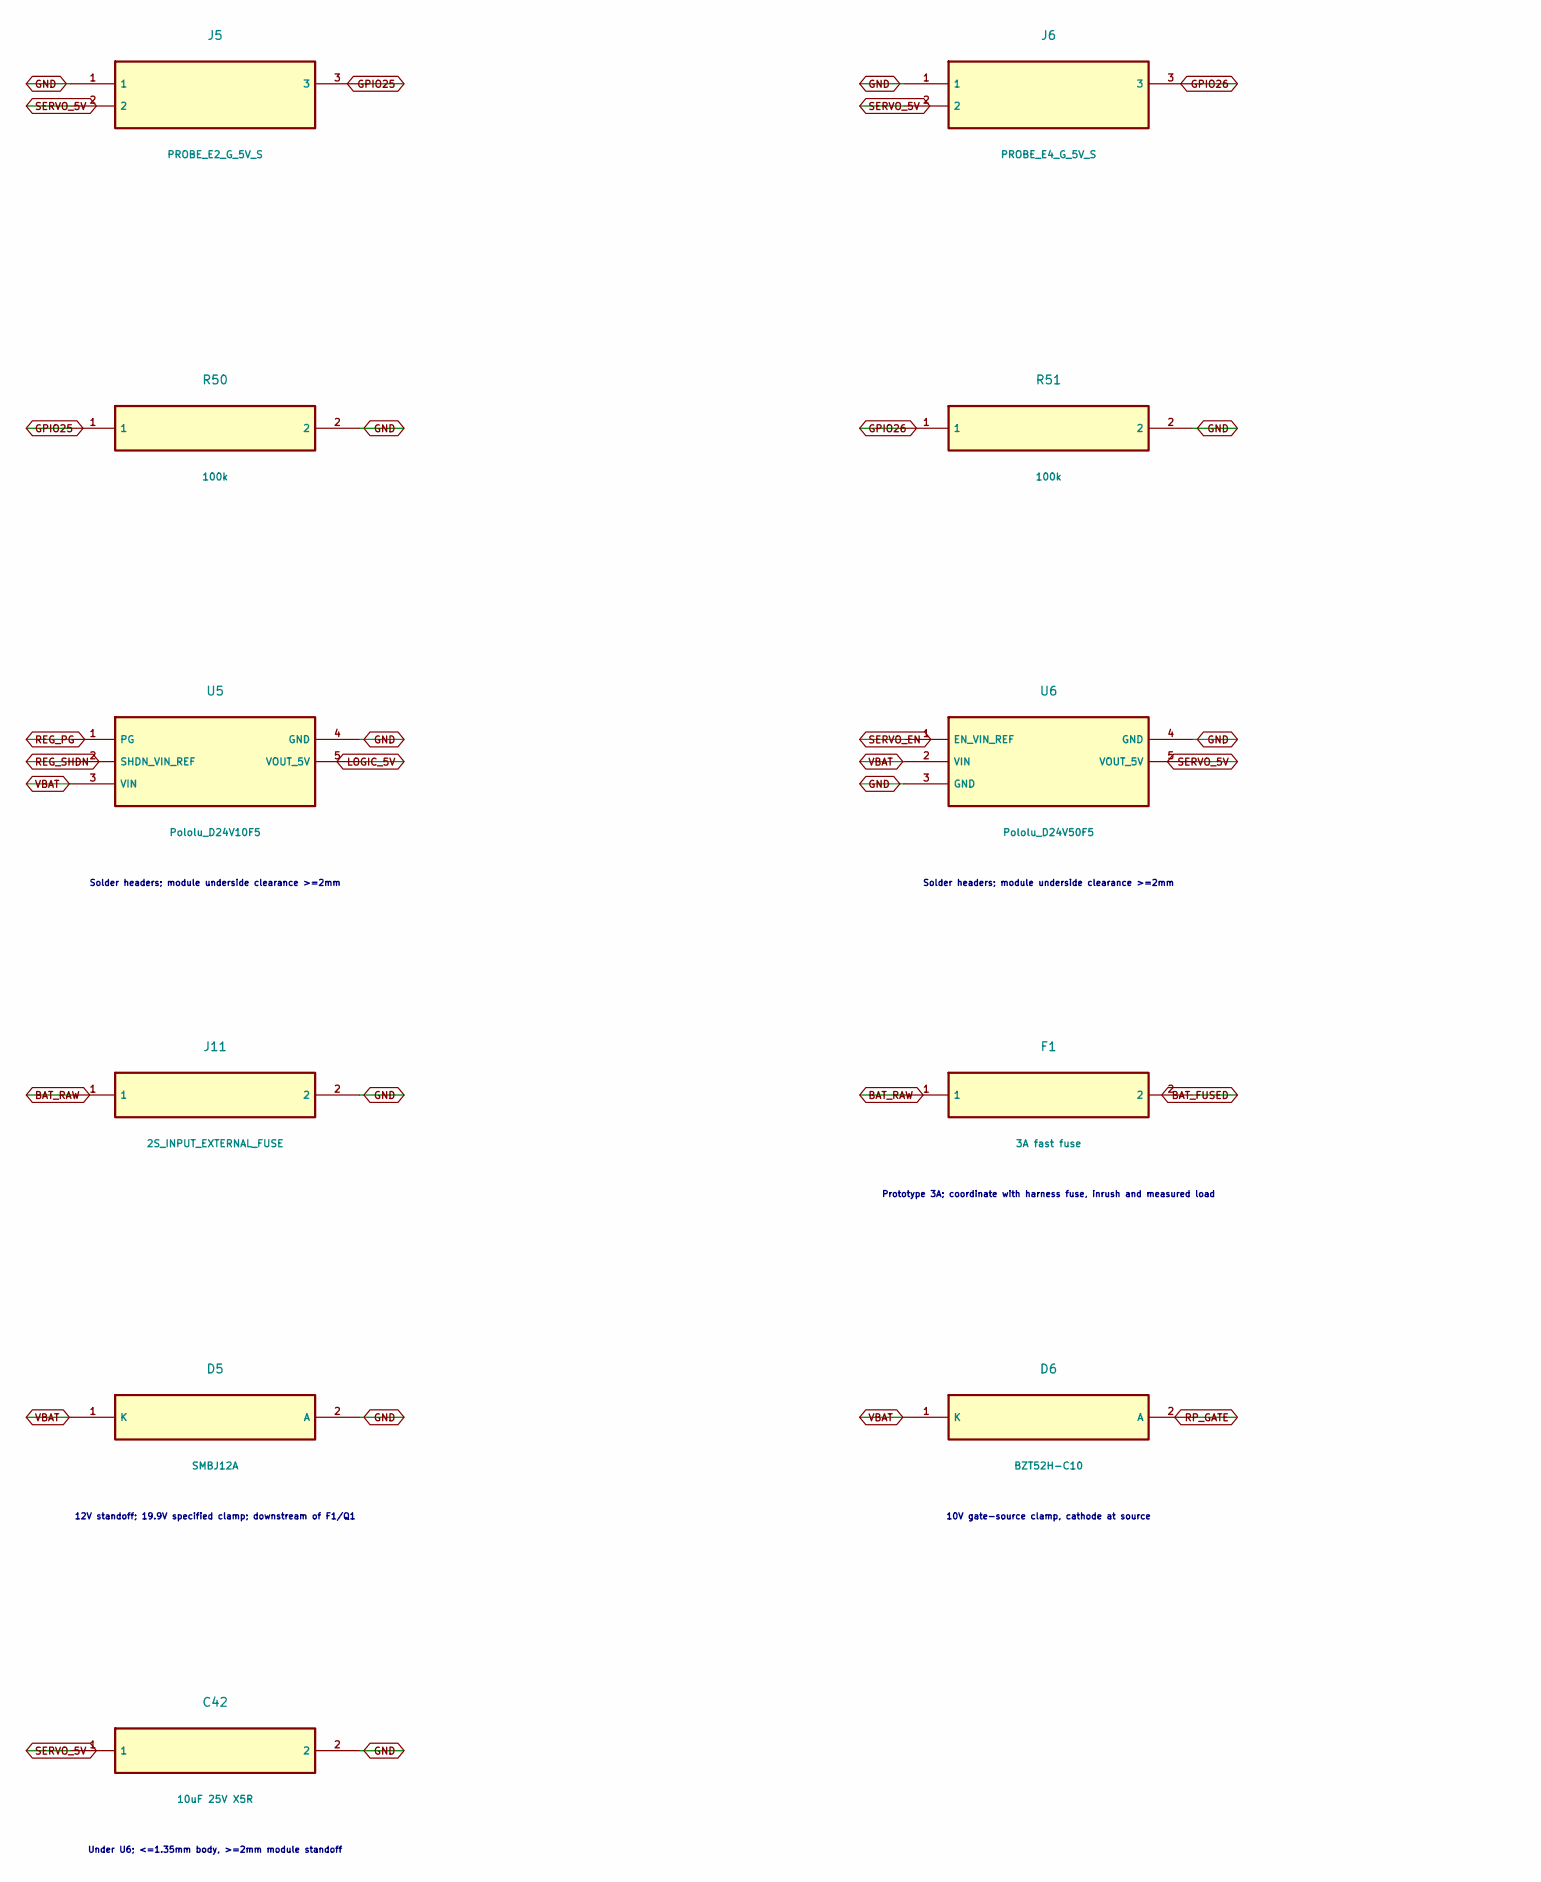
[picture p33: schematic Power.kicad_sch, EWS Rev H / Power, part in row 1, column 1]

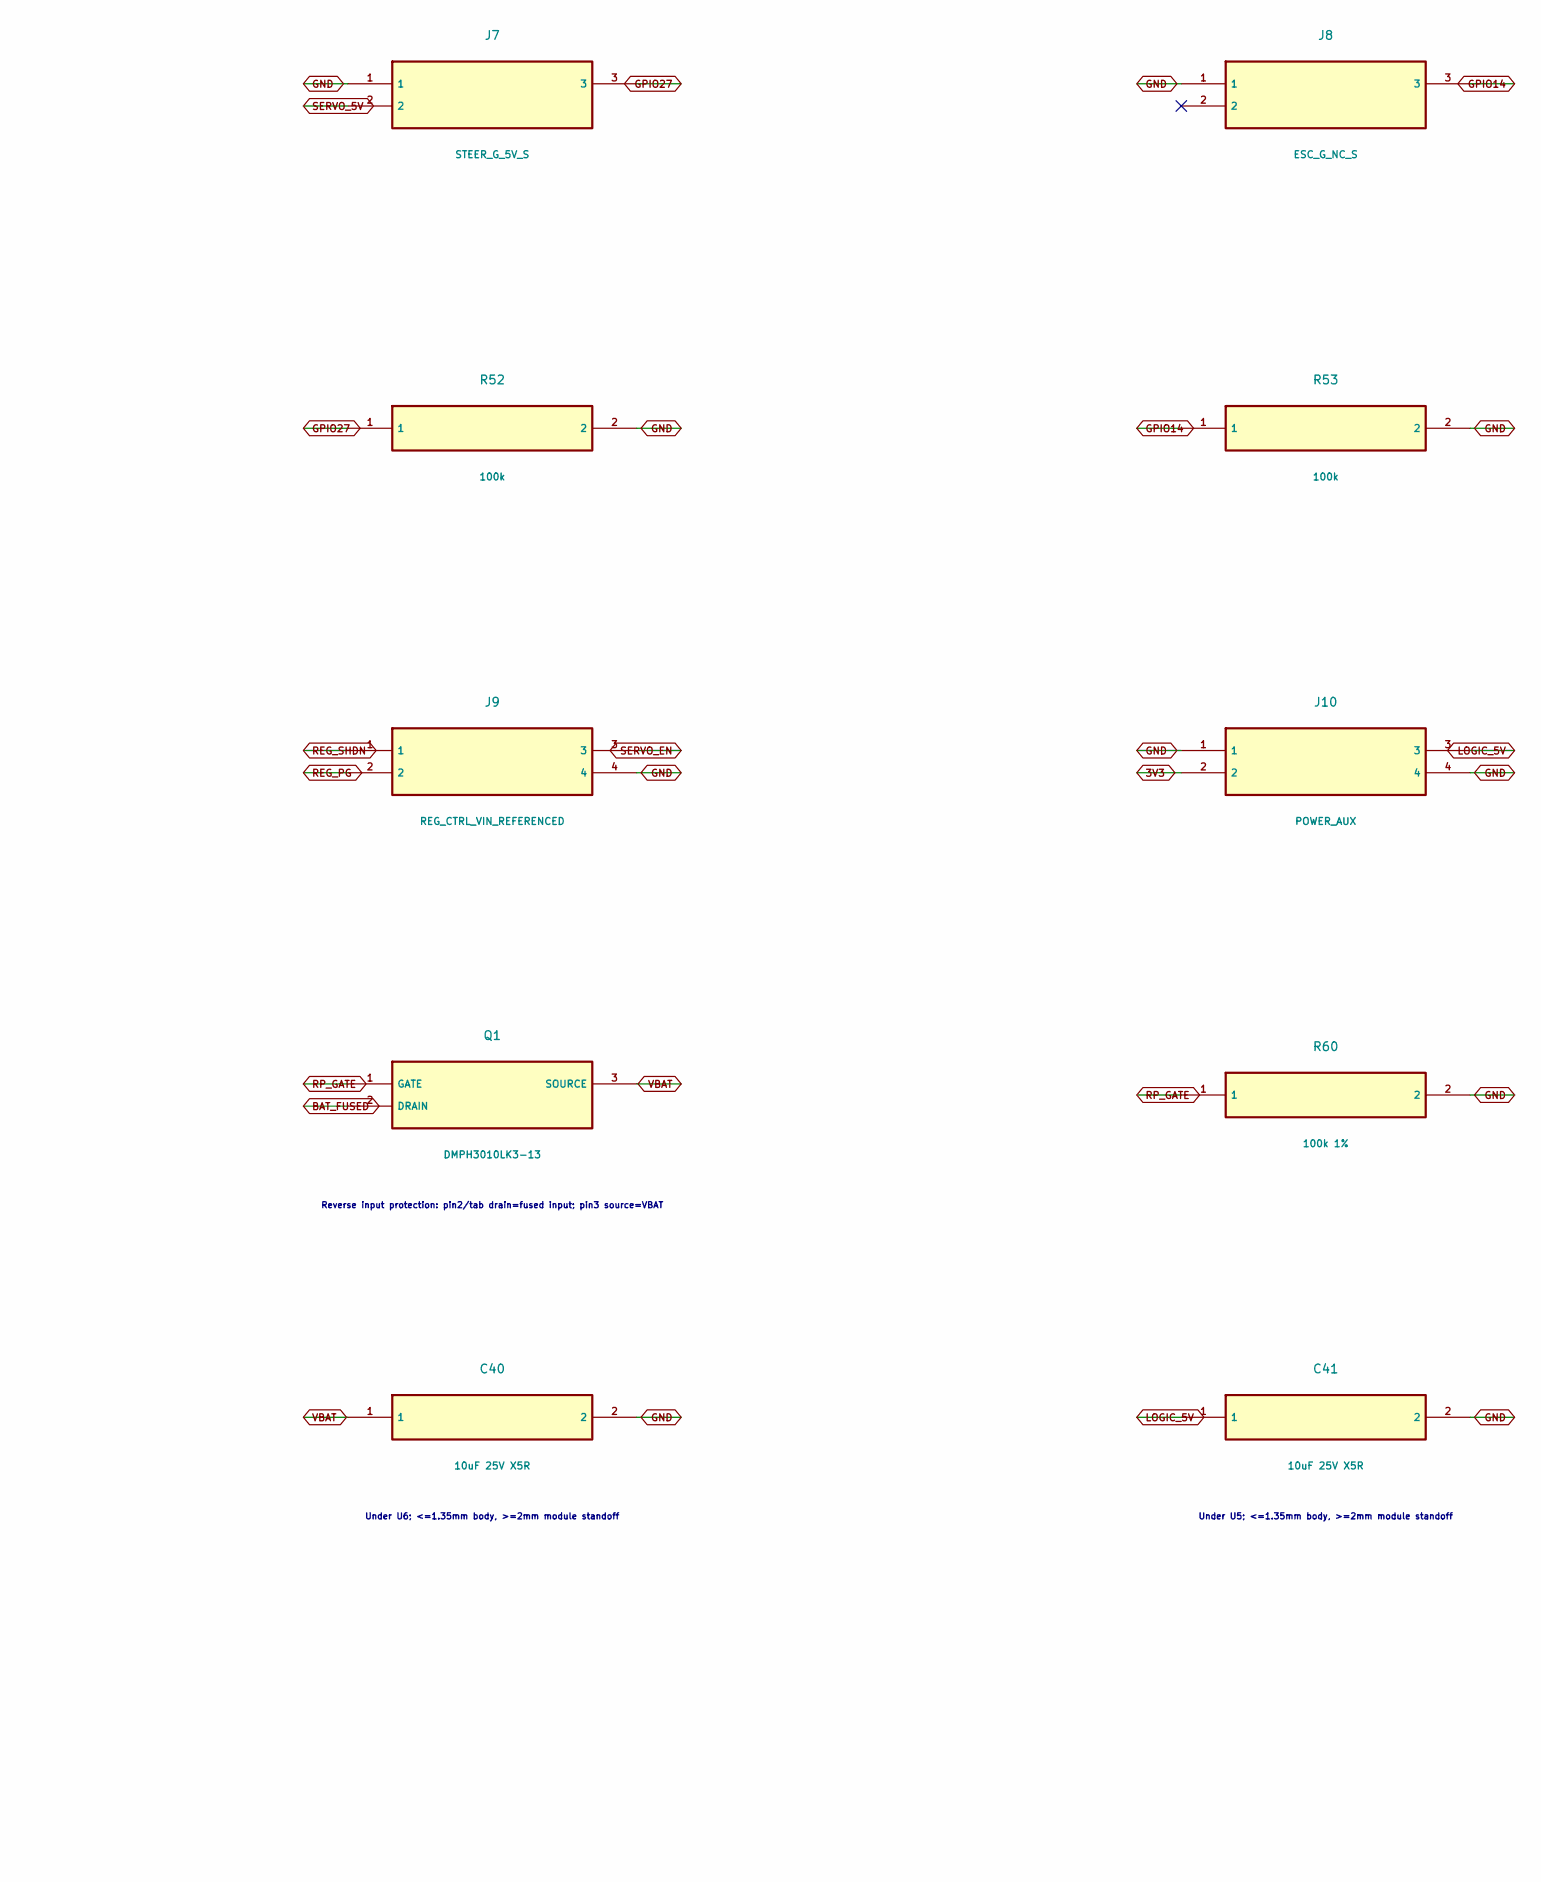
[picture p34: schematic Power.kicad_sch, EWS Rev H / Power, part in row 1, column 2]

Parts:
C40: 10uF 25V X5R; C40
C41: 10uF 25V X5R; C41
C42: 10uF 25V X5R; C42
D5: SMBJ12A; D5
D6: BZT52H-C10; D6
F1: 3A fast fuse; F1
J5: PROBE_E2_G_5V_S; J5
J6: PROBE_E4_G_5V_S; J6
J7: STEER_G_5V_S; J7
J8: ESC_G_NC_S; J8
J9: REG_CTRL_VIN_REFERENCED; J9
J10: POWER_AUX; J10
J11: 2S_INPUT_EXTERNAL_FUSE; J11
Q1: DMPH3010LK3-13; Q1
R50: 100k; R50
R51: 100k; R51
R52: 100k; R52
R53: 100k; R53
R60: 100k 1%; R60
U5: Pololu_D24V10F5; U5
U6: Pololu_D24V50F5; U6

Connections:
3V3: J10.2; also elsewhere on the board
BAT_FUSED: F1.2, Q1.2 (DRAIN)
BAT_RAW: F1.1, J11.1
GND: C40.2, C41.2, C42.2, D5.2 (A), J5.1, J6.1, J7.1, J8.1, J9.4, J10.1, J10.4, J11.2, R50.2, R51.2, R52.2, R53.2, R60.2, U5.4 (GND), U6.3 (GND), U6.4 (GND); also elsewhere on the board
GPIO14: J8.3, R53.1; also elsewhere on the board
GPIO25: J5.3, R50.1; also elsewhere on the board
GPIO26: J6.3, R51.1; also elsewhere on the board
GPIO27: J7.3, R52.1; also elsewhere on the board
LOGIC_5V: C41.1, J10.3, U5.5 (VOUT_5V); also elsewhere on the board
REG_PG: J9.2, U5.1 (PG)
REG_SHDN: J9.1, U5.2 (SHDN_VIN_REF)
RP_GATE: D6.2 (A), Q1.1 (GATE), R60.1
SERVO_5V: C42.1, J5.2, J6.2, J7.2, U6.5 (VOUT_5V)
SERVO_EN: J9.3, U6.1 (EN_VIN_REF)
VBAT: C40.1, D5.1 (K), D6.1 (K), Q1.3 (SOURCE), U5.3 (VIN), U6.2 (VIN); also elsewhere on the board

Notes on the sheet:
Solder headers; module underside clearance >=2mm
Prototype 3A; coordinate with harness fuse, inrush and measured load
Reverse input protection: pin2/tab drain=fused input; pin3 source=VBAT
12V standoff; 19.9V specified clamp; downstream of F1/Q1
10V gate-source clamp, cathode at source
Under U6; <=1.35mm body, >=2mm module standoff
Under U5; <=1.35mm body, >=2mm module standoff

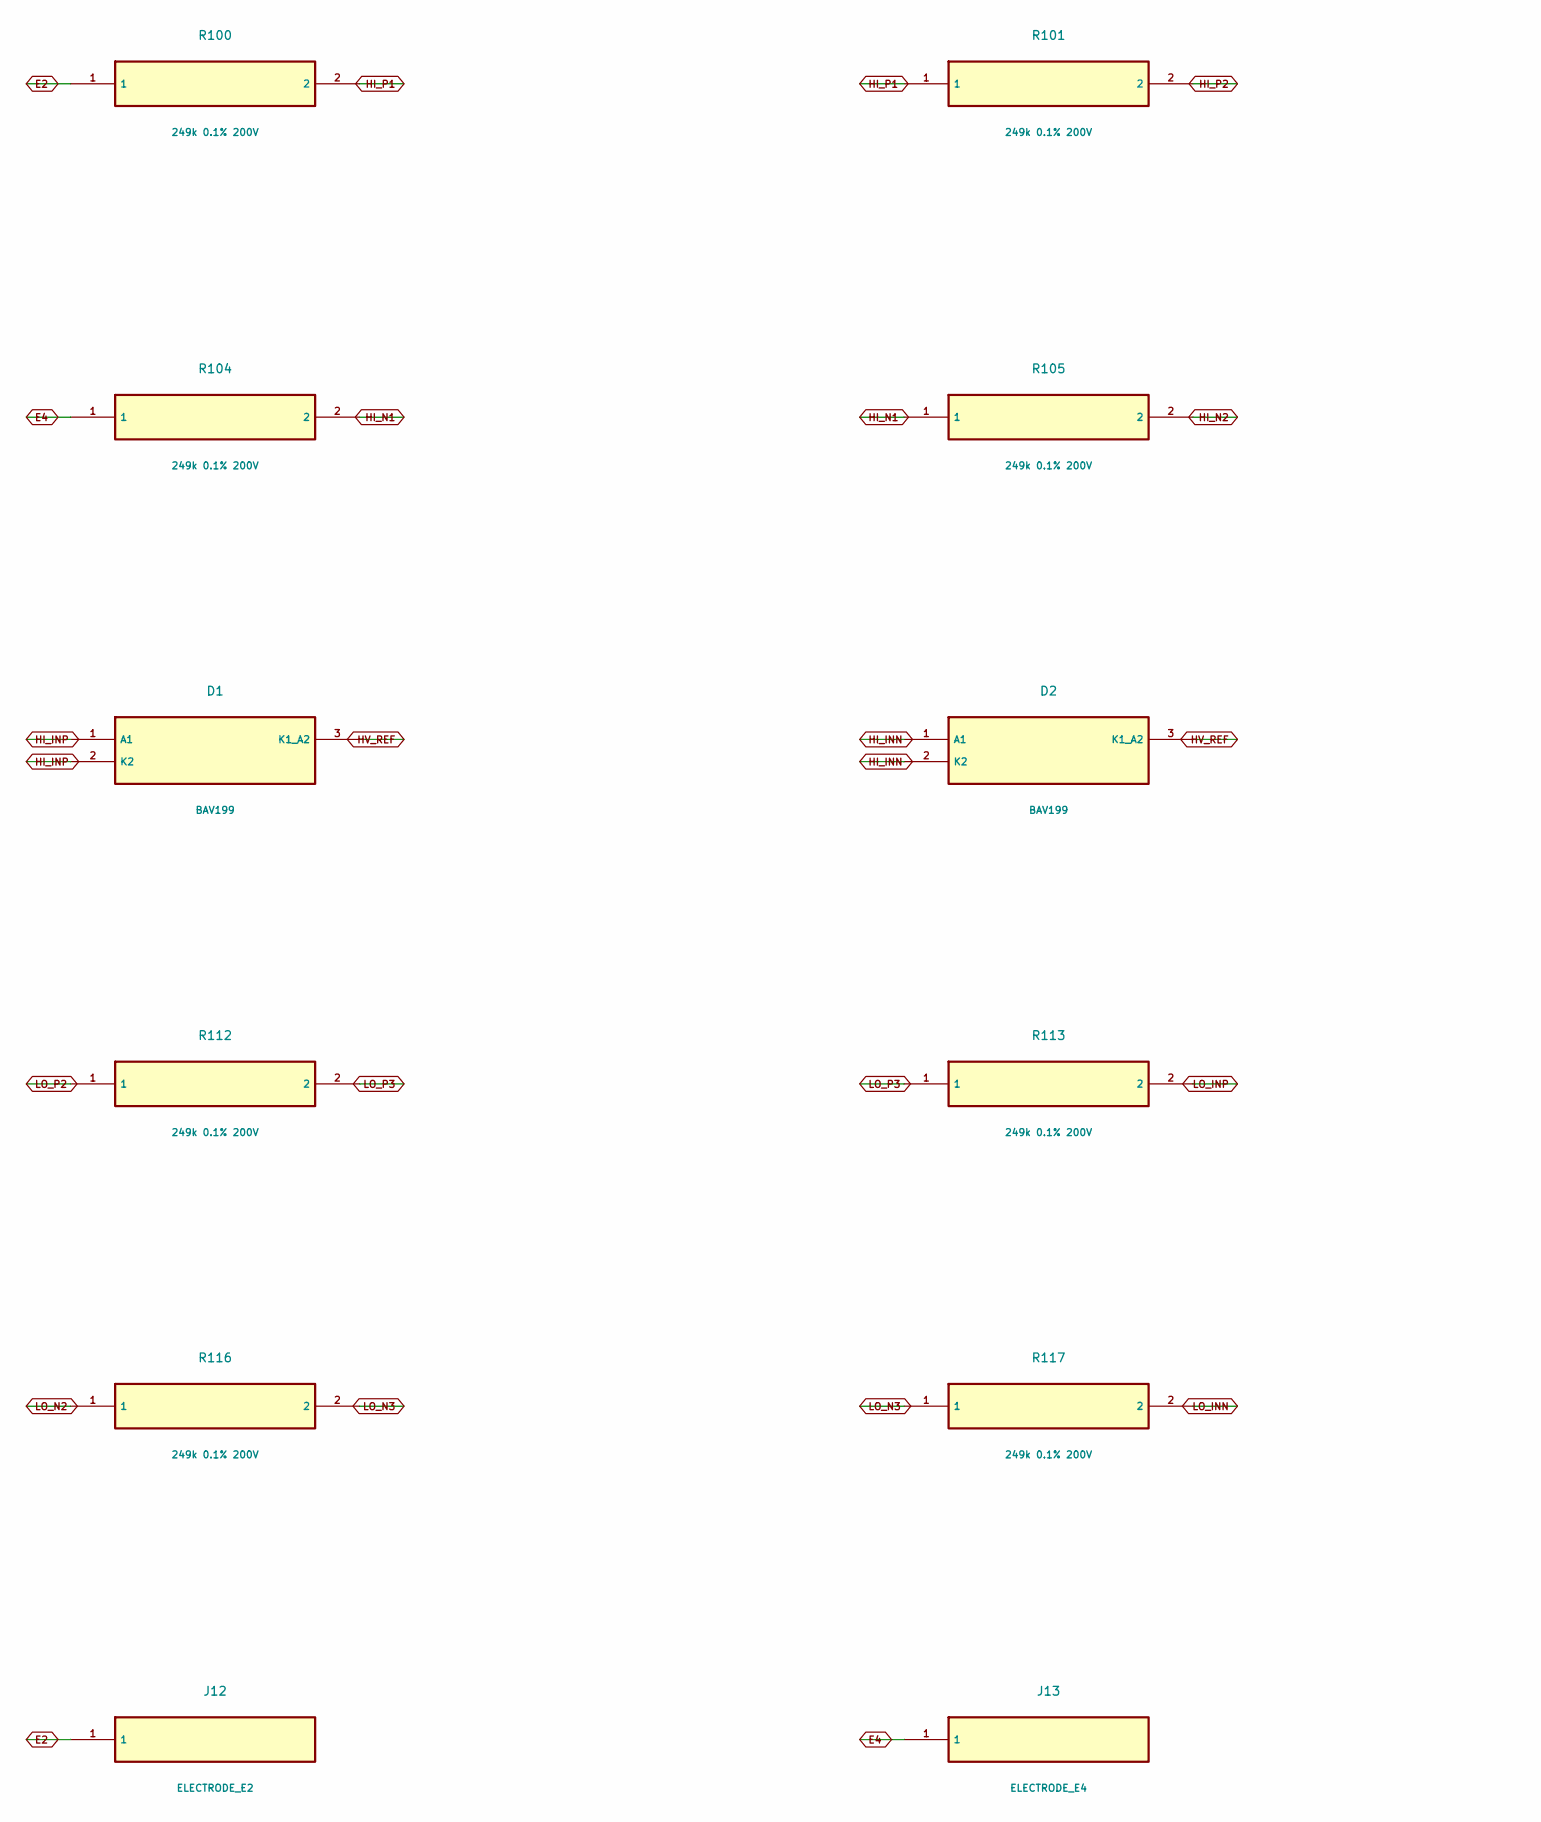
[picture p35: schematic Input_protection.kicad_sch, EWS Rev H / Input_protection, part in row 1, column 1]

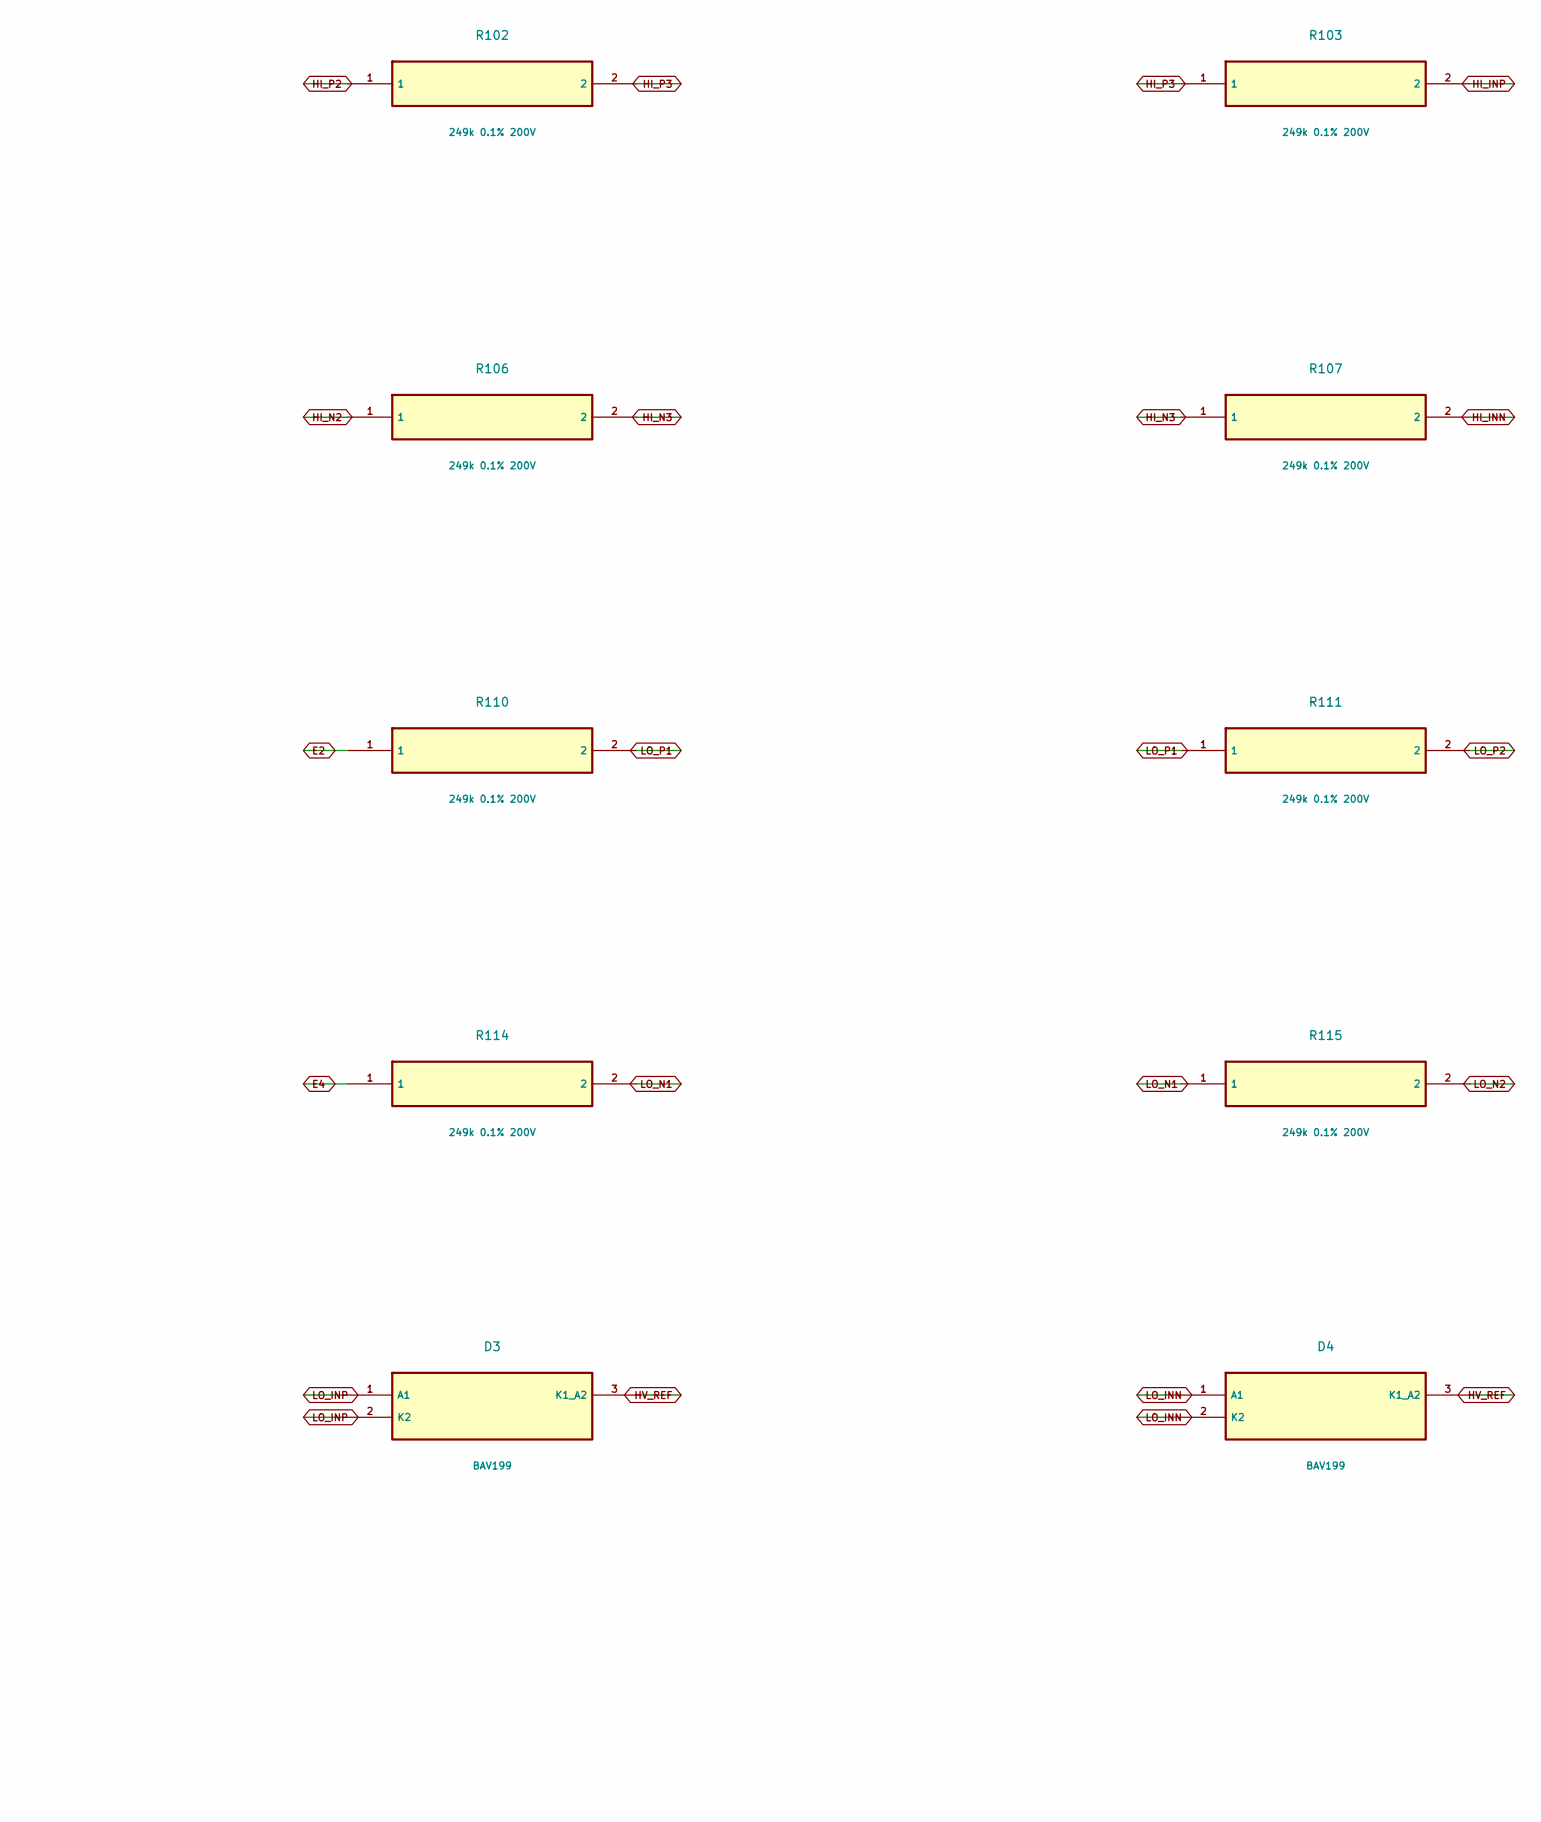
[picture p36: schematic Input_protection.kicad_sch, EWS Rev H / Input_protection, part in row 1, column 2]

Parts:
D1: BAV199; D1
D2: BAV199; D2
D3: BAV199; D3
D4: BAV199; D4
J12: ELECTRODE_E2; J12
J13: ELECTRODE_E4; J13
R100: 249k 0.1% 200V; R100
R101: 249k 0.1% 200V; R101
R102: 249k 0.1% 200V; R102
R103: 249k 0.1% 200V; R103
R104: 249k 0.1% 200V; R104
R105: 249k 0.1% 200V; R105
R106: 249k 0.1% 200V; R106
R107: 249k 0.1% 200V; R107
R110: 249k 0.1% 200V; R110
R111: 249k 0.1% 200V; R111
R112: 249k 0.1% 200V; R112
R113: 249k 0.1% 200V; R113
R114: 249k 0.1% 200V; R114
R115: 249k 0.1% 200V; R115
R116: 249k 0.1% 200V; R116
R117: 249k 0.1% 200V; R117

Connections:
E2: J12.1, R100.1, R110.1
E4: J13.1, R104.1, R114.1
HI_INN: D2.1 (A1), D2.2 (K2), R107.2; also elsewhere on the board
HI_INP: D1.1 (A1), D1.2 (K2), R103.2; also elsewhere on the board
HI_N1: R104.2, R105.1
HI_N2: R105.2, R106.1
HI_N3: R106.2, R107.1
HI_P1: R100.2, R101.1
HI_P2: R101.2, R102.1
HI_P3: R102.2, R103.1
HV_REF: D1.3 (K1_A2), D2.3 (K1_A2), D3.3 (K1_A2), D4.3 (K1_A2); also elsewhere on the board
LO_INN: D4.1 (A1), D4.2 (K2), R117.2; also elsewhere on the board
LO_INP: D3.1 (A1), D3.2 (K2), R113.2; also elsewhere on the board
LO_N1: R114.2, R115.1
LO_N2: R115.2, R116.1
LO_N3: R116.2, R117.1
LO_P1: R110.2, R111.1
LO_P2: R111.2, R112.1
LO_P3: R112.2, R113.1

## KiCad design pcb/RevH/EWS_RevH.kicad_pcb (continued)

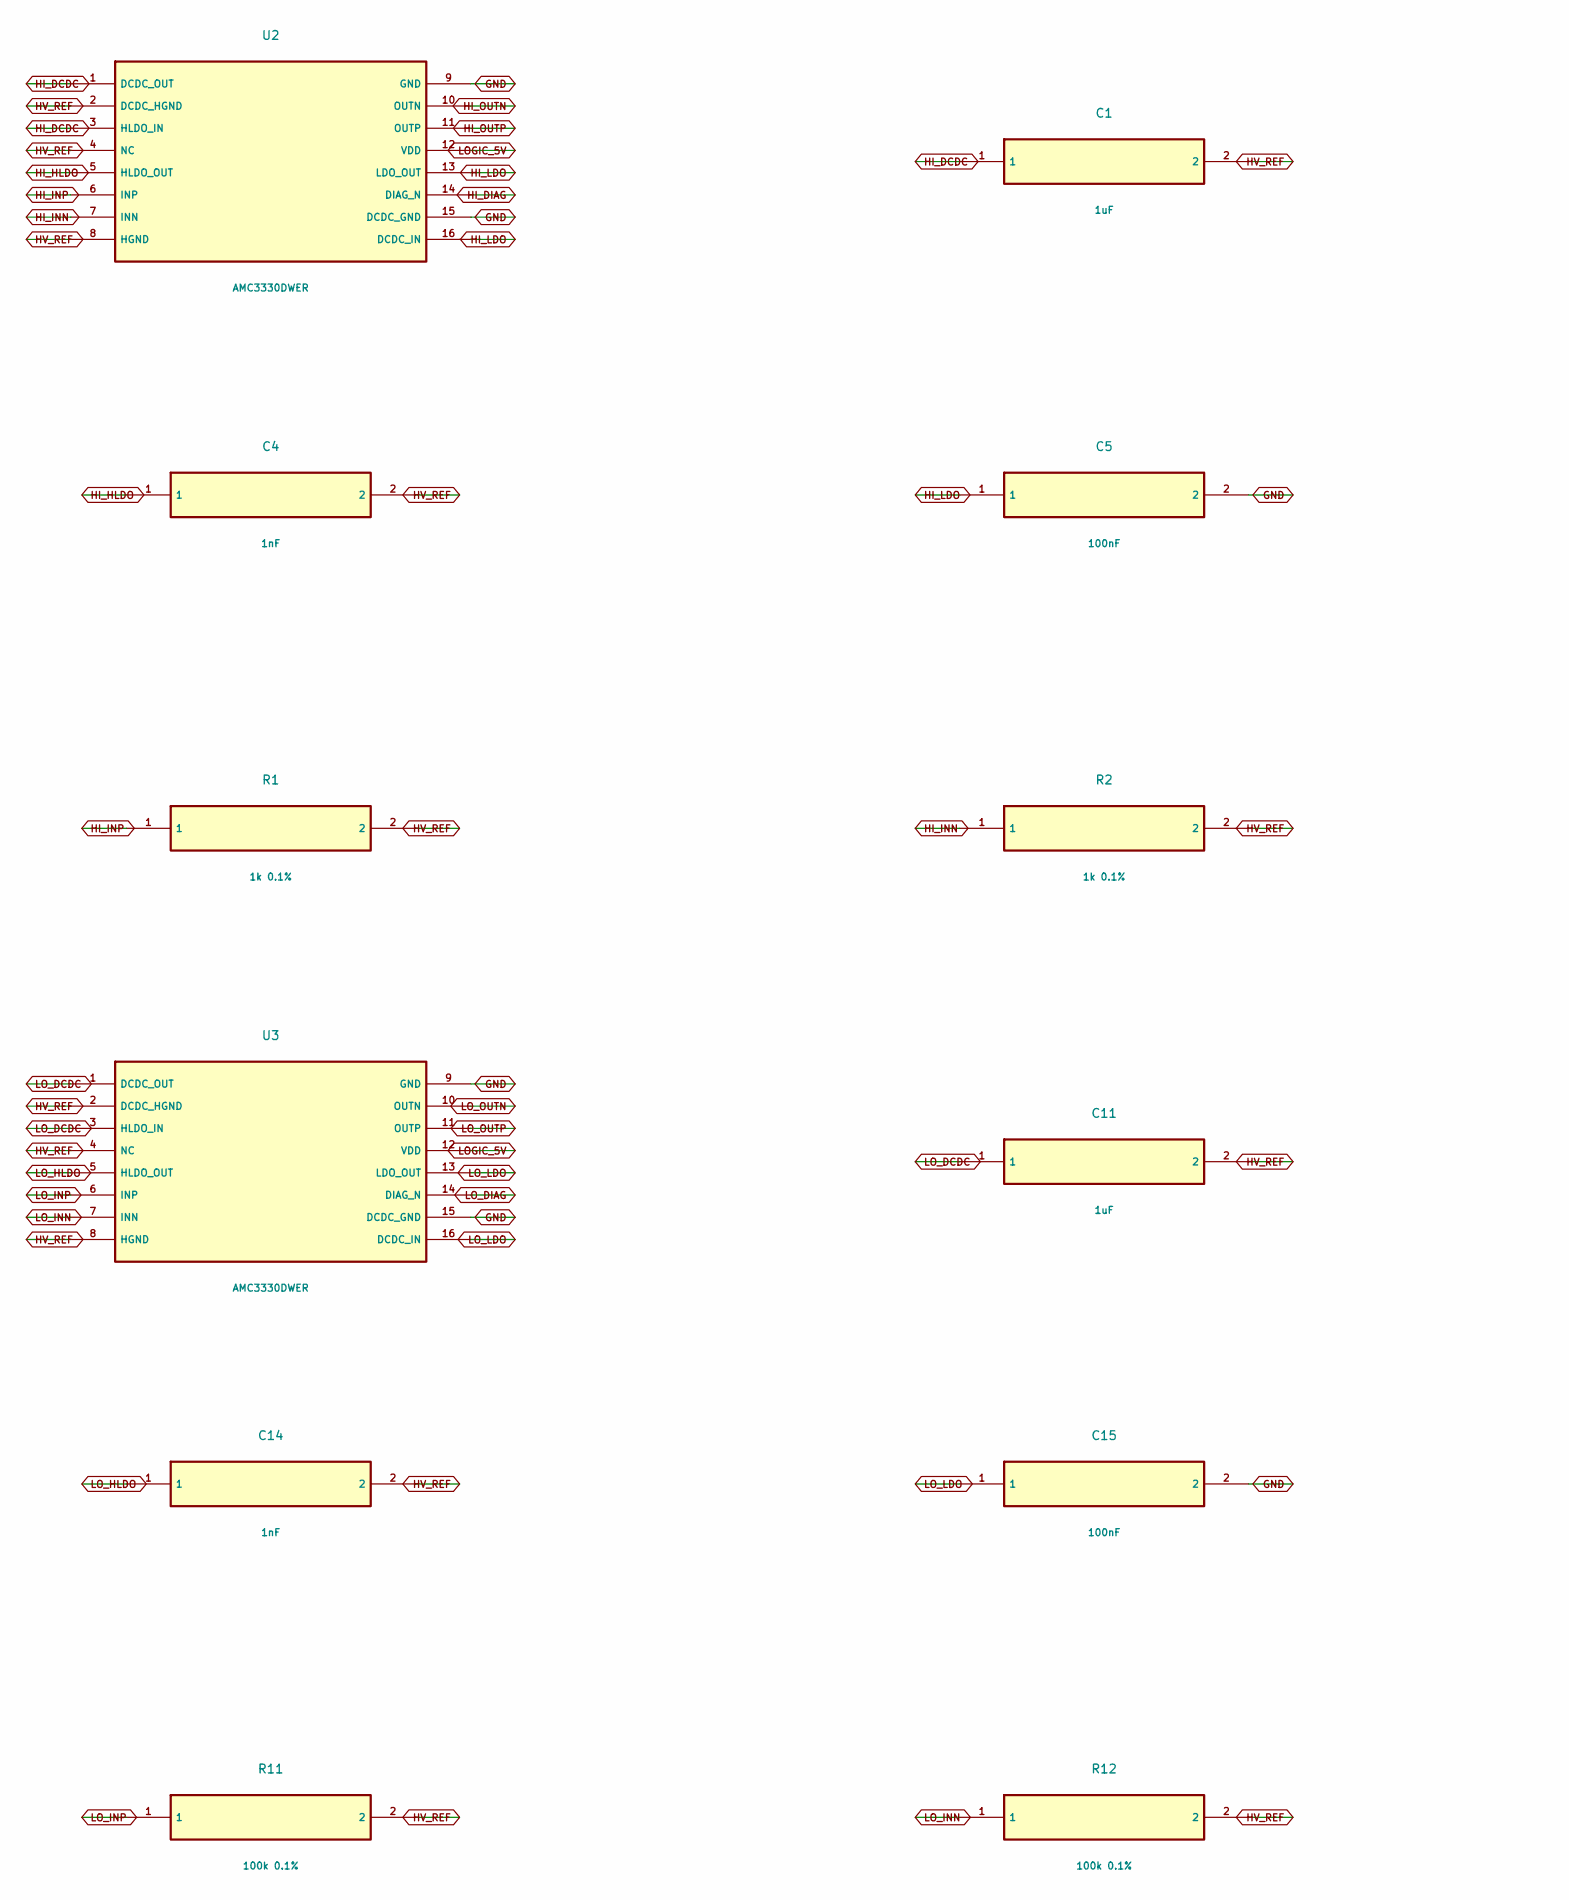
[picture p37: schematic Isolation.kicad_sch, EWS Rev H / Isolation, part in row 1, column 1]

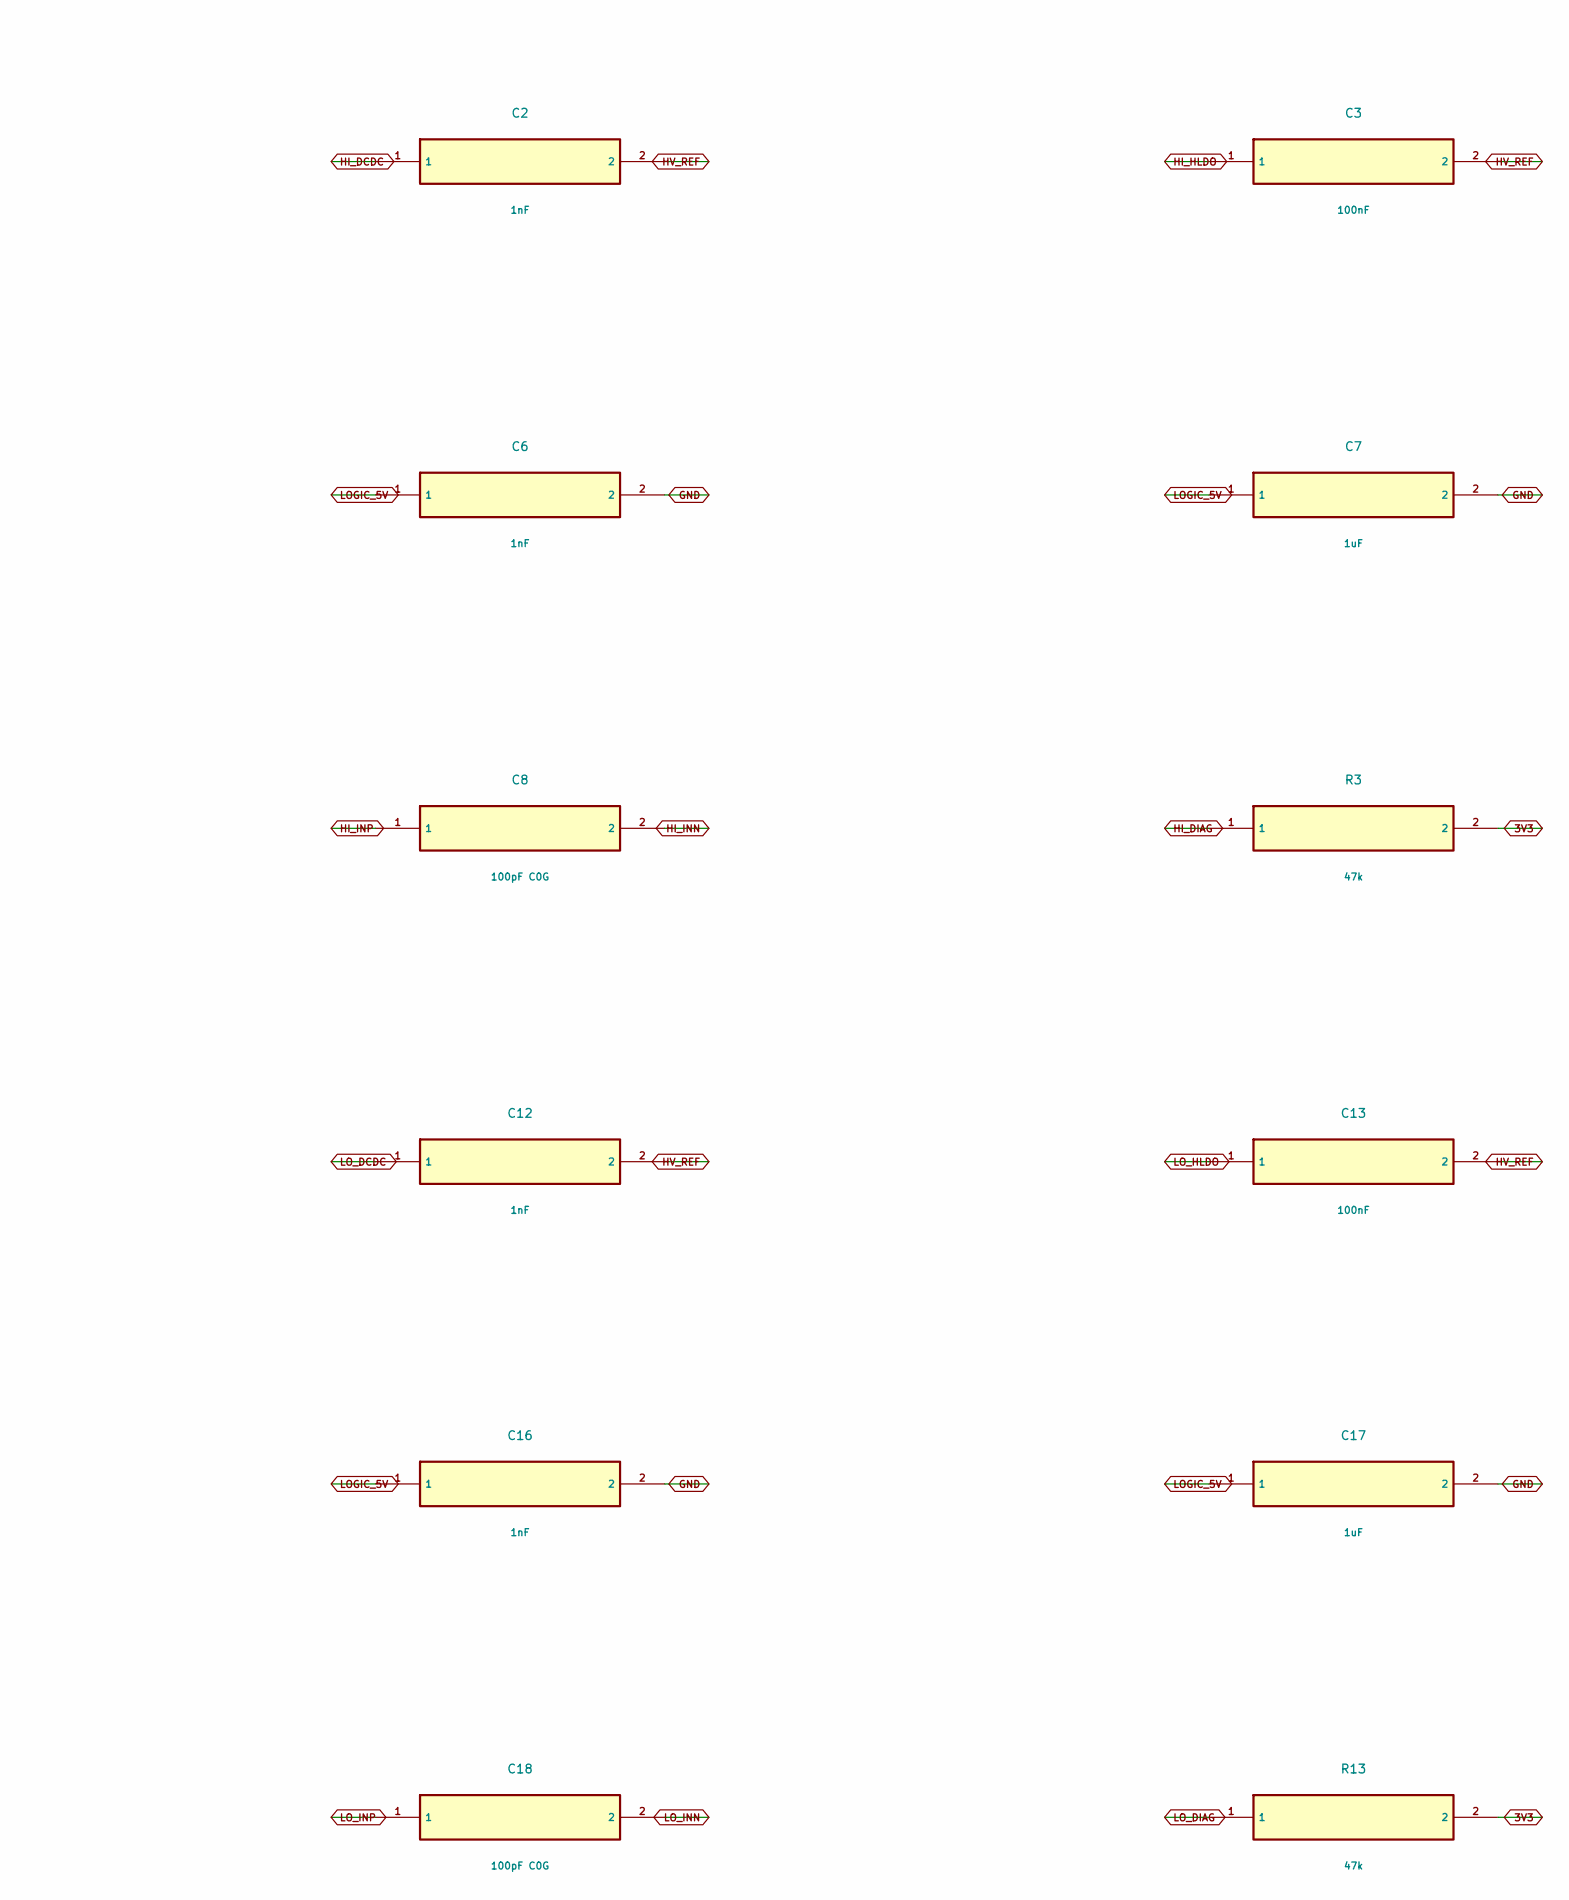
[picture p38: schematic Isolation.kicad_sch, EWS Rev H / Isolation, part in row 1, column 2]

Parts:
C1: 1uF; C1
C2: 1nF; C2
C3: 100nF; C3
C4: 1nF; C4
C5: 100nF; C5
C6: 1nF; C6
C7: 1uF; C7
C8: 100pF C0G; C8
C11: 1uF; C11
C12: 1nF; C12
C13: 100nF; C13
C14: 1nF; C14
C15: 100nF; C15
C16: 1nF; C16
C17: 1uF; C17
C18: 100pF C0G; C18
R1: 1k 0.1%; R1
R2: 1k 0.1%; R2
R3: 47k; R3
R11: 100k 0.1%; R11
R12: 100k 0.1%; R12
R13: 47k; R13
U2: AMC3330DWER; U2
U3: AMC3330DWER; U3

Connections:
3V3: R3.2, R13.2; also elsewhere on the board
GND: C5.2, C6.2, C7.2, C15.2, C16.2, C17.2, U2.9 (GND), U2.15 (DCDC_GND), U3.9 (GND), U3.15 (DCDC_GND); also elsewhere on the board
HI_DCDC: C1.1, C2.1, U2.1 (DCDC_OUT), U2.3 (HLDO_IN)
HI_DIAG: R3.1, U2.14 (DIAG_N); also elsewhere on the board
HI_HLDO: C3.1, C4.1, U2.5 (HLDO_OUT)
HI_INN: C8.2, R2.1, U2.7 (INN); also elsewhere on the board
HI_INP: C8.1, R1.1, U2.6 (INP); also elsewhere on the board
HI_LDO: C5.1, U2.13 (LDO_OUT), U2.16 (DCDC_IN)
HI_OUTN: U2.10 (OUTN); also elsewhere on the board
HI_OUTP: U2.11 (OUTP); also elsewhere on the board
HV_REF: C1.2, C2.2, C3.2, C4.2, C11.2, C12.2, C13.2, C14.2, R1.2, R2.2, R11.2, R12.2, U2.2 (DCDC_HGND), U2.4 (NC), U2.8 (HGND), U3.2 (DCDC_HGND), U3.4 (NC), U3.8 (HGND); also elsewhere on the board
LOGIC_5V: C6.1, C7.1, C16.1, C17.1, U2.12 (VDD), U3.12 (VDD); also elsewhere on the board
LO_DCDC: C11.1, C12.1, U3.1 (DCDC_OUT), U3.3 (HLDO_IN)
LO_DIAG: R13.1, U3.14 (DIAG_N); also elsewhere on the board
LO_HLDO: C13.1, C14.1, U3.5 (HLDO_OUT)
LO_INN: C18.2, R12.1, U3.7 (INN); also elsewhere on the board
LO_INP: C18.1, R11.1, U3.6 (INP); also elsewhere on the board
LO_LDO: C15.1, U3.13 (LDO_OUT), U3.16 (DCDC_IN)
LO_OUTN: U3.10 (OUTN); also elsewhere on the board
LO_OUTP: U3.11 (OUTP); also elsewhere on the board

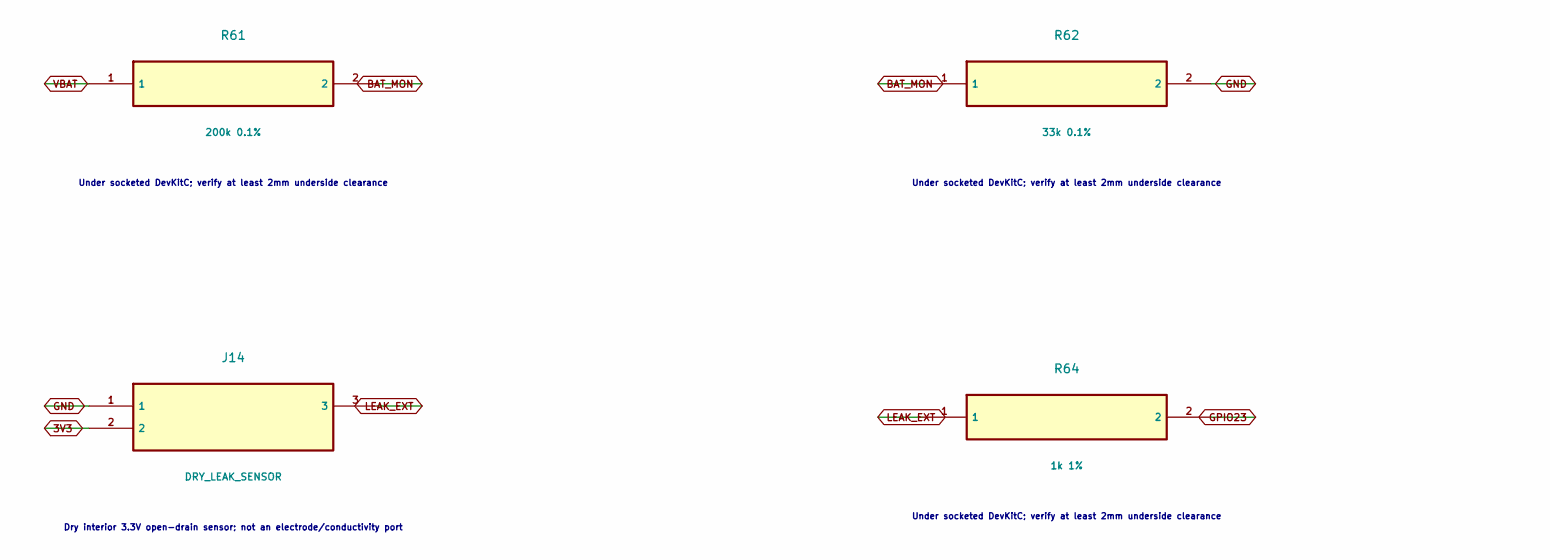
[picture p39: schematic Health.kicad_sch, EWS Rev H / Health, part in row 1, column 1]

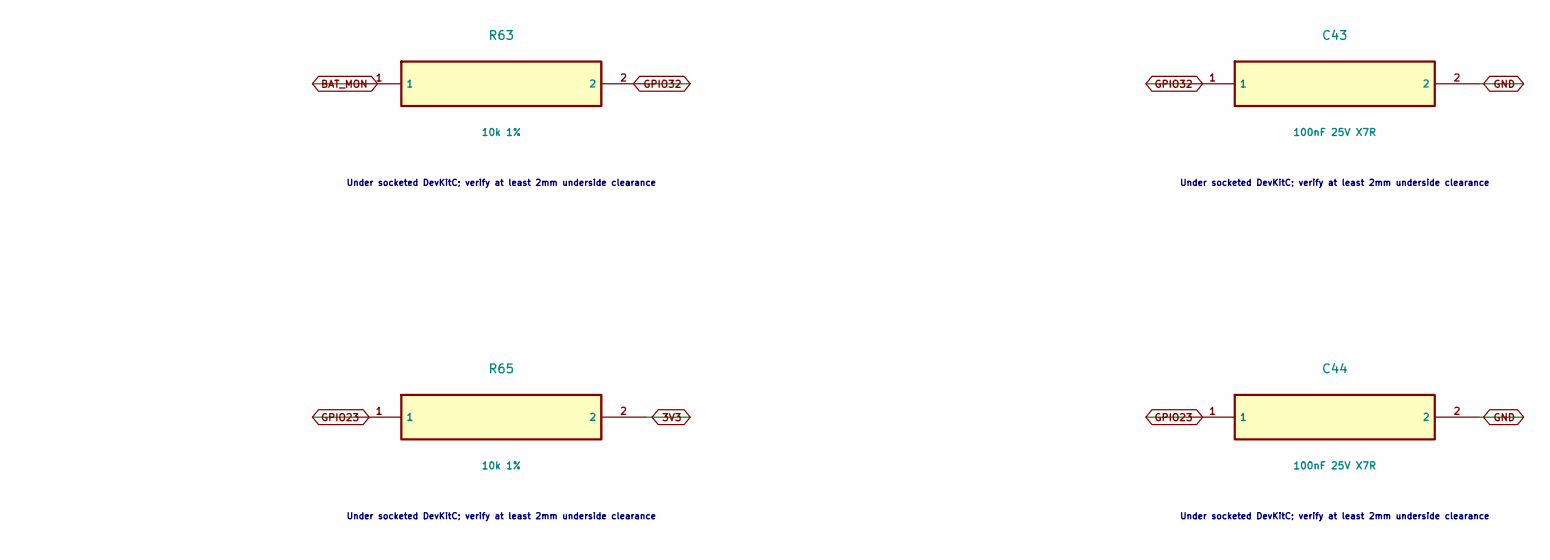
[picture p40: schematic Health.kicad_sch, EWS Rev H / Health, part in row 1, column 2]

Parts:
C43: 100nF 25V X7R; C43
C44: 100nF 25V X7R; C44
J14: DRY_LEAK_SENSOR; J14
R61: 200k 0.1%; R61
R62: 33k 0.1%; R62
R63: 10k 1%; R63
R64: 1k 1%; R64
R65: 10k 1%; R65

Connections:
3V3: J14.2, R65.2; also elsewhere on the board
BAT_MON: R61.2, R62.1, R63.1
GND: C43.2, C44.2, J14.1, R62.2; also elsewhere on the board
GPIO23: C44.1, R64.2, R65.1; also elsewhere on the board
GPIO32: C43.1, R63.2; also elsewhere on the board
LEAK_EXT: J14.3, R64.1
VBAT: R61.1; also elsewhere on the board

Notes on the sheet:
Under socketed DevKitC; verify at least 2mm underside clearance
Dry interior 3.3V open-drain sensor; not an electrode/conductivity port

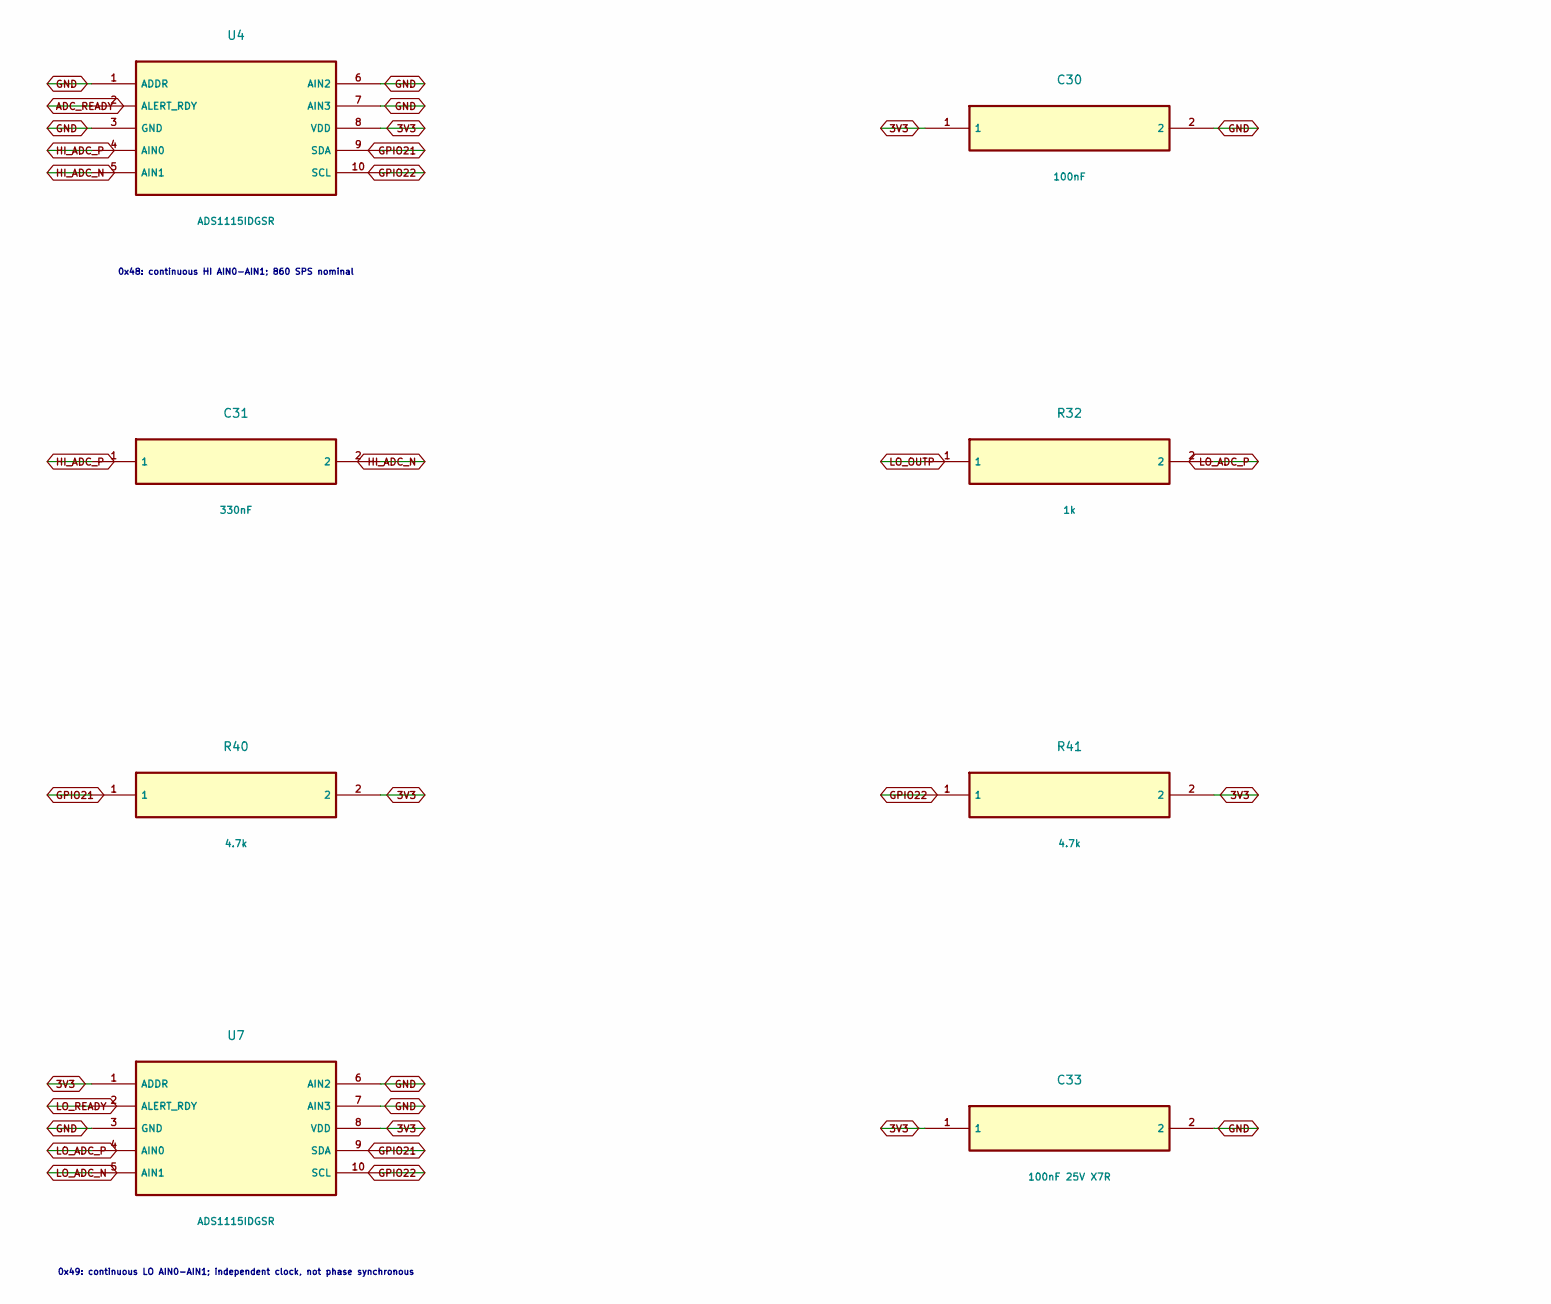
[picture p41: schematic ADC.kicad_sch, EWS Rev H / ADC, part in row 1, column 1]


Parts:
C30: 100nF; C30
C31: 330nF; C31
C32: 330nF; C32
C33: 100nF 25V X7R; C33
J4: ADC_DIAGNOSTICS; J4
R30: 1k; R30
R31: 1k; R31
R32: 1k; R32
R33: 1k; R33
R40: 4.7k; R40
R41: 4.7k; R41
R42: 10k; R42
R43: 10k 1%; R43
U4: ADS1115IDGSR; U4
U7: ADS1115IDGSR; U7

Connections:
3V3: C30.1, C33.1, J4.2, R40.2, R41.2, R42.2, R43.2, U4.8 (VDD), U7.1 (ADDR), U7.8 (VDD); also elsewhere on the board
ADC_READY: J4.5, R42.1, U4.2 (ALERT_RDY); also elsewhere on the board
GND: C30.2, C33.2, J4.1, U4.1 (ADDR), U4.3 (GND), U4.6 (AIN2), U4.7 (AIN3), U7.3 (GND), U7.6 (AIN2), U7.7 (AIN3); also elsewhere on the board
GPIO21: R40.1, U4.9 (SDA), U7.9 (SDA); also elsewhere on the board
GPIO22: R41.1, U4.10 (SCL), U7.10 (SCL); also elsewhere on the board
HI_ADC_N: C31.2, J4.7, R31.2, U4.5 (AIN1)
HI_ADC_P: C31.1, J4.6, R30.2, U4.4 (AIN0)
HI_DIAG: J4.3; also elsewhere on the board
HI_OUTN: R31.1; also elsewhere on the board
HI_OUTP: R30.1; also elsewhere on the board
LO_ADC_N: C32.2, J4.9, R33.2, U7.5 (AIN1)
LO_ADC_P: C32.1, J4.8, R32.2, U7.4 (AIN0)
LO_DIAG: J4.4; also elsewhere on the board
LO_OUTN: R33.1; also elsewhere on the board
LO_OUTP: R32.1; also elsewhere on the board
LO_READY: R43.1, U7.2 (ALERT_RDY); also elsewhere on the board

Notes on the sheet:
0x48: continuous HI AIN0-AIN1; 860 SPS nominal
0x49: continuous LO AIN0-AIN1; independent clock, not phase synchronous


Board: 6 copper layers, 91.0 x 124.0 mm, 100 parts (0 on the bottom side), 74 nets.

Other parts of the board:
H1: M3 nylon hardware; H1
H2: M3 nylon hardware; H2
H3: M3 nylon hardware; H3
H4: M3 nylon hardware; H4
M1: Hobbywing WP1625 on SJ3550; M1

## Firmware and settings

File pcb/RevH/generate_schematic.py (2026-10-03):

from pathlib import Path
import json,uuid,math
OUT=Path(__file__).resolve().parent
parts=json.loads((OUT/'component_manifest.json').read_text())
def uid(s):return str(uuid.uuid5(uuid.NAMESPACE_DNS,'EWS.RevH.'+s))
def q(s):return json.dumps(str(s))
def fx(size=1):return f'(effects (font (size {size} {size})))'
rootid=uid('root')
pages={
 'Control': [z for z in parts if z['ref'] in ['U1','J1','J2','J3','JP1']],
 'Power': [z for z in parts if z['ref'] in ['U5','U6','J5','J6','J7','J8','J9','J10','J11','R50','R51','R52','R53','Q1','F1','D5','D6','R60','C40','C41','C42']],
 'Input_protection':[z for z in parts if z['ref'] in ['J12','J13','D1','D2','D3','D4'] or (z['ref'].startswith('R') and int(z['ref'][1:])>=100)],
 'Isolation':[z for z in parts if z['ref'] in ['U2','U3'] or (z['group'] in ['HI','LO'] and not z['ref'].startswith('D')) or z['ref'] in ['R3','R13','C5','C6','C7','C15','C16','C17']],
}
pages['Health']=[z for z in parts if z['ref'] in ['J14','R61','R62','R63','C43','R64','R65','C44']]
used={z['ref'] for pp in pages.values() for z in pp}
pages['ADC']=[z for z in parts if z['ref'] not in used and not z['ref'].startswith('H')]
pages['Control'].append(dict(ref='#FLG01',value='PWR_FLAG_JP1_FITTED',footprint='',pins={'1':'ESP_5V'},uuid=uid('power_flag'),note='Power is present only with JP1 fitted. Remove JP1 before USB.'))
assert len([z['ref'] for pp in pages.values() for z in pp])==len(set(z['ref'] for pp in pages.values() for z in pp))
pin_names={
'U1':dict(enumerate(['3V3','EN','GPIO36_IN','GPIO39_IN','GPIO34_IN','GPIO35_IN','GPIO32','GPIO33','GPIO25','GPIO26','GPIO27','GPIO14','GPIO12_STRAP','GND','GPIO13','FLASH9_RESERVED','FLASH10_RESERVED','FLASH11_RESERVED','5V','GND','GPIO23','GPIO22','TX0','RX0','GPIO21','GND','GPIO19','GPIO18','GPIO5_STRAP','GPIO17_WROOM','GPIO16_WROOM','GPIO4','GPIO0_BOOT','GPIO2_STRAP','GPIO15_STRAP','FLASH8_RESERVED','FLASH7_RESERVED','FLASH6_RESERVED'],1)),
'U2':dict(enumerate(['DCDC_OUT','DCDC_HGND','HLDO_IN','NC','HLDO_OUT','INP','INN','HGND','GND','OUTN','OUTP','VDD','LDO_OUT','DIAG_N','DCDC_GND','DCDC_IN'],1)),
'U4':dict(enumerate(['ADDR','ALERT_RDY','GND','AIN0','AIN1','AIN2','AIN3','VDD','SDA','SCL'],1)),
'U5':dict(enumerate(['PG','SHDN_VIN_REF','VIN','GND','VOUT_5V'],1)),
'U6':dict(enumerate(['EN_VIN_REF','VIN','GND','GND','VOUT_5V'],1))}
pin_names['U3']=pin_names['U2']
pin_names['U7']=pin_names['U4']
pin_names['Q1']={1:'GATE',2:'DRAIN',3:'SOURCE'}
pin_names['D5']={1:'K',2:'A'}
pin_names['D6']={1:'K',2:'A'}
def pintype(z,num):
    ref=z['ref'];n=int(num)
    if ref.startswith('#'):return 'power_out'
    if ref in ('U2','U3'):
        return {1:'power_out',2:'passive',3:'power_in',4:'passive',5:'power_out',6:'input',7:'input',8:'passive',9:'passive',10:'output',11:'output',12:'power_in',13:'power_out',14:'open_collector',15:'passive',16:'power_in'}[n]
    if ref=='U1':return 'power_out' if n==1 else ('power_in' if n==19 else ('input' if n in [2,3,4,5,6] else 'bidirectional'))
    if ref in ('U4','U7'):return {1:'input',2:'open_collector',3:'passive',4:'input',5:'input',6:'input',7:'input',8:'power_in',9:'bidirectional',10:'input'}[n]
    if ref=='U5':return {1:'open_collector',2:'input',3:'passive',4:'passive',5:'power_out'}[n]
    if ref=='U6':return {1:'input',2:'passive',3:'passive',4:'passive',5:'power_out'}[n]
    return 'passive'
def symbol(z):
    ref=z['ref'];nn=len(z['pins']);nr=math.ceil(nn/2);h=max(5.08,(nr+1)*2.54);w=17.78 if nn>10 else 11.43
    geom=[]; coords={}
    for i,(num,net) in enumerate(z['pins'].items()):
        left=i<nr; row=i if left else i-nr;yy=h/2-2.54*(row+1);xx=(-w-5.08) if left else(w+5.08);angle=0 if left else 180
        pname=pin_names.get(ref,{}).get(int(num),str(num))
        if ref in ('D1','D2','D3','D4'):pname={1:'A1',2:'K2',3:'K1_A2'}[int(num)]
        geom.append(f'(pin {pintype(z,num)} line (at {xx} {yy} {angle}) (length 5.08) (name {q(pname)} {fx(.8)}) (number {q(num)} {fx(.8)}))')
        coords[num]=(xx,yy,left)
    lib=f'''(symbol "EWS:{ref}" (pin_names (offset 0.5)) (in_bom yes) (on_board yes)
    (property "Reference" {q(ref)} (at 0 {h/2+3} 0) {fx()})
    (property "Value" {q(z['value'])} (at 0 {-h/2-3} 0) {fx(.8)})
    (property "Footprint" {q(z['footprint'])} (at 0 0 0) (effects (font (size 1 1)) hide))
    (symbol "{ref}_0_1" (rectangle (start {-w} {h/2}) (end {w} {-h/2}) (stroke (width .254) (type default)) (fill (type background))))
    (symbol "{ref}_1_1" {''.join(geom)}))'''
    return lib,coords,h
def base(pageid,title,paper='A3'):
    return f'''(kicad_sch (version 20250114) (generator "eeschema") (uuid {pageid}) (paper "{paper}")
    (title_block (title {q(title)}) (rev "H prototype") (company "IoT Beyond Lab") (comment 1 "Engineering prototype - qualification required"))'''
all_libs=[]
for pagenu,(name,pp) in enumerate(pages.items(),2):
    pageid=uid(name);symbols=[];instances=[];labels=[]
    cols=3 if name=='Control' else 4
    cellw=125 if name=='Control' else 96
    cellh=85 if name=='Control' else 38
    for idx,z in enumerate(pp):
        lib,coords,h=symbol(z);symbols.append(lib);all_libs.append(lib.replace('"EWS:'+z['ref']+'"','"'+z['ref']+'"',1))
        xx=round((cellw*(idx%cols)+cellw/2+10)/1.27)*1.27; yy=round((48+cellh*(idx//cols))/1.27)*1.27
        labels.append(f'(text {q(z["note"][:85])} (at {xx} {yy+h/2+9} 0) {fx(.7)})' if z['note'] else '')
        instances.append(f'''(symbol (lib_id "EWS:{z['ref']}") (at {xx} {yy} 0) (unit 1) (in_bom yes) (on_board yes) (dnp no) (uuid {z['uuid']})
        (property "Reference" {q(z['ref'])} (at {xx} {yy-h/2-3} 0) {fx()})
        (property "Value" {q(z['value'])} (at {xx} {yy+h/2+3} 0) {fx(.8)})
        (property "Footprint" {q(z['footprint'])} (at {xx} {yy} 0) (effects (font (size 1 1)) hide))
        (instances (project "EWS_RevH" (path "/{rootid}/{pageid}" (reference {q(z['ref'])}) (unit 1)))))''')
        for num,(dx,dy,left) in coords.items():
            net=z['pins'][num]; px=xx+dx;py=yy-dy; ex=px+(-5.08 if left else 5.08)
            if net.startswith('FLASH') or net=='ESC_BEC_NC':
                labels.append(f'(no_connect (at {px} {py}) (uuid {uid(z["ref"]+num+"nc")}))');continue
            labels.append(f'(wire (pts (xy {px} {py}) (xy {ex} {py})) (stroke (width 0) (type default)) (uuid {uid(z["ref"]+num+"w")}))')
            labels.append(f'(global_label {q(net)} (shape bidirectional) (at {ex} {py} {0 if left else 180}) (effects (font (size .8 .8)) (justify {"left" if left else "right"})) (uuid {uid(z["ref"]+num+"l")}))')
    content=base(pageid,'EWS Rev H / '+name)+'\n(lib_symbols '+''.join(symbols)+')\n'+''.join(instances)+''.join(labels)+')'
    if name=='Control':
        content=content.replace('(symbol "EWS:#FLG01" (pin_names (offset 0.5)) (in_bom yes) (on_board yes)', '(symbol "EWS:#FLG01" (pin_names (offset 0.5)) (in_bom no) (on_board no)')
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

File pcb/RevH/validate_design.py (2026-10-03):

"""Run with KiCad 10 Python from this directory; DRC/ERC require kicad-cli."""
from pathlib import Path
import json,pcbnew as p
root=Path(__file__).resolve().parent
b=p.LoadBoard(str(root/'EWS_RevH.kicad_pcb'))
parts=json.loads((root/'component_manifest.json').read_text())
fps={f.GetReference():f for f in b.GetFootprints()}
assert b.GetCopperLayerCount()==6
assert abs(p.ToMM(b.GetDesignSettings().GetBoardThickness())-2)<1e-6
count=0
for z in parts:
 for pin,net in z['pins'].items():
  if net.startswith('FLASH') or net=='ESC_BEC_NC':continue
  pads=[a for a in fps[z['ref']].Pads() if a.GetNumber()==pin]
  assert pads,(z['ref'],pin)
  assert all(a.GetNetname()==net for a in pads),(z['ref'],pin,net)
  count+=len(pads)
for r,x,y in [('H1',33,158.5),('H2',117,158.5),('H3',33,41.5),('H4',117,41.5)]:
 a=next(iter(fps[r].Pads()))
 assert abs(p.ToMM(a.GetPosition().x)-x)<1e-6 and abs(p.ToMM(a.GetPosition().y)-y)<1e-6
 assert abs(p.ToMM(a.GetDrillSize().x)-3.4)<1e-6
print(f'{count} electrical pins match manifest; six layers, 2mm thickness and mounting datums verified')

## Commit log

2026-09-24 Fix Rev-A mechanical interfaces and document verified Rev-A.1 exports
    [Energized_Water_Scanner_RevA.f3d, Energized_Water_Scanner_RevA.step, Energized_Water_Scanner_RevA1.f3d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]
2026-09-24 Compact hull to 320 x 170 mm and verify Rev-B service layout
    [Energized_Water_Scanner_RevB.f3d, Energized_Water_Scanner_RevB.step, PRINT_01_Hull_shell.stl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]
2026-09-24 Improve tray harness restraints and document production assembly audit
    [Energized_Water_Scanner_RevB1.f3d, Energized_Water_Scanner_RevB1.step, PRINT_03_Removable_electronics_tray.stl]
2026-09-25 Document prioritized steps and acceptance gates for working prototype
2026-09-25 Rev-B.2: add electrode access, screw retention and hull branding
    [Energized_Water_Scanner_RevB2.f3d, Energized_Water_Scanner_RevB2.step, PRINT_01_Hull_shell.stl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]
2026-09-25 Rev-B.3: document assembly corrections and unresolved build gates
2026-09-25 Rev-B.3: record measured corrections, assembly blockers and printer plan
2026-09-25 Add verified Rev-B.3 editable CAD and STEP
    [Energized_Water_Scanner_RevB3.f3d, Energized_Water_Scanner_RevB3.step]
2026-09-25 Update three print parts and complete STL bundle
    [PRINT_01_Hull_shell.stl, PRINT_04_Battery_slide_tray.stl, PRINT_18_ESP32_capture_bridge.stl]
2026-09-25 Add Rev-B.3 assembly and interface previews
2026-09-25 Add E2 motor-support coupon instructions
2026-09-25 Add verified E2 motor-support fit coupon
    [COUPON_01_E2_motor_mount_hull_section.stl]
2026-09-26 Audit supplier geometry and correct Rev-B.4 mechanical interfaces
    Verify BOM dimensions against manufacturer drawings and CAD, clear regulator pin access in PRINT_20, correct M4 nut envelopes, and resolve regulator family STEP provenance. Include native CAD, print exports, repeatable audits, source evidence, replacement proposals, and explicit remaining assembly gates.
    [Energized_Water_Scanner_RevB4.f3d, Energized_Water_Scanner_RevB4.step, PRINT_20_Regulator_capture_bridge.stl]
2026-09-26 Design Rev-C.1 articulated four-probe prototype
    [Energized_Water_Scanner_RevC1.f3d, Energized_Water_Scanner_RevC1.step, PRINT_01_Hull_shell.stl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]
2026-09-27 Redesign Rev-D with internal servos and recessed probe channels
    [Energized_Water_Scanner_RevD.f3d, Energized_Water_Scanner_RevD.step, PRINT_01_Hull_shell.stl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]
2026-09-28 Document saved Rev-E1 hull leakage repairs and build holds
    [BOM.csv, BOM.xlsx]
2026-10-01 Add current Fusion audit and service inspection photos
    Native viewport PNGs show the current physical assembly, corrected wiring allocations and staged battery-service space. No CAD or mesh exports are included.
2026-10-01 Document live component audit and service fixes
    Audit manufacturer nominal dimensions and identify uncertain procurement interfaces. Correct the staged battery removal, USB access, wiring routes and current electronics-only sheet description. Record 145-solid static checks, sampled probe/battery movement and remaining flotation/sealing holds. BOM and all 3D files remain unchanged.
2026-10-01 Link current audit and electronics procurement summary
    Point to the saved live Fusion audit, current native inspection photo and cleaned 11-item electronics sheet. Keep the complete BOM and historical 3D files unchanged.
2026-10-01 Add saved Rev-E2 physical correction photos
    Native Fusion viewport photos show the forward controller shelf, raised battery cradle and printed wire restraints. Images only; no 3D exports or BOM changes.
2026-10-01 Show final cradle installation clearances
    Refresh native Fusion viewport photos after the cradle side and aft stock relief. The battery, cradle and assembled cassette now have checked removal paths. PNG photos only.
2026-10-01 Document saved Rev-E2 physical service corrections
    Describe the five revised print bodies, forward controller, raised battery, blind mounting bosses, wire saddles and cradle extraction relief. Record current fastener coordinates, 145-solid static checks, probe and service-path checks, and remaining hardware holds. BOM and all 3D files stay unchanged.
2026-10-01 Link current Rev-E2 physical corrections and photos
    Describe the saved live Fusion revision and identify the five revised print geometries. Link the physical correction report and current photos. Keep the complete BOM and historical CAD/print files unchanged.
2026-10-01 Document Rev-F two-probe layout and rear controller with Fusion photos
2026-10-02 Record live tray PCB geometry and dual-range sensing requirements
    [EWS_mechanical_template.kicad_pcb]
2026-10-02 Integrate Rev G dual-range PCB and remove obsolete controller mounts
    [ADC.kicad_sch, BOM.csv, Control.kicad_sch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]
2026-10-03 Rev H: improve dual-range acquisition and power protection; consolidate current documentation
    [ADC.kicad_sch, ASSEMBLY_BOM.csv, BOM.csv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]
2026-10-04 Document saved Rev I Fusion fit audit and reconcile assembly BOMs
    [ASSEMBLY_BOM.csv, BOM.csv]
2026-10-04 Correct hull audit after closing bow stern and chine breakthroughs
    [BOM.csv]
